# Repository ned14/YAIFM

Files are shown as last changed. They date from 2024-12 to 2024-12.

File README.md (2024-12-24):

# A remix of AndBu/YAIFM

His original can be found at: https://github.com/AndBu/YAIFM

The differences here:

1. No switches, we detect the motor stopping turning instead.
2. No switches means fewer parts need printing or assembling,
though we still use the motor housing and retention
clip untouched from AndBu.
3. Because we now rely on the blind 'jamming' to detect
when it is fully open, we need to use a metal cog as
the plastic isn't strong enough.
4. We have ESPHome figure out blind fully open after
first power on. It stores in flash what you tell it blind
fully closed is. After that, you can request '10% open'
or '50% closed' or whatever as usual within Home Assistant
and you'll get exactly that.

To tl;dr; the differences, we go for simpler hardware and
let the software do all the heavy lifting. I reckon total
BOM cost per blind is under €40 inc VAT delivered excluding
the 5v power supply (you can use any existing USB based
phone charger).

Thingiverse link: https://www.thingiverse.com/thing:6865302

Printables link: https://www.printables.com/model/1120003-ikea-fridans-motorisation

Detailed instructions: https://www.nedprod.com/Niall_stuff/vdiary/archives/1734888387.html

## Bill of Materials

1. A GA12-N20 motor with rotary encoder which runs at
50 RPM at 6v, and has around 1 kgf.cm of torque at normal
load. You probably will want one with as much torque
at stall as possible without consuming too much current,
this lets the motor 'push through' any badly furled blinds
or the 200 cm long model fully extended to 195 cm.
Aliexpress is probably your easiest choice here, there are
many GA12-N20 models to choose between. Mine cost about
€6 inc VAT delivered.

2. A DRV8833 dual H-Bridge motor driver. I used the one on
a breakout board called 'HW-627' which is very affordable,
also from Aliexpress for about €2 inc VAT delivered.

3. A ‘9 Teeth D Type’ metal cog which has an outer diameter
of 8 mm and is 7.4 mm long. The key measurement is between
the flat part of the D hole rising perpendicularly to the
topmost of the rounded part of the D hole – that needs to
be 2.4 mm if you want it loose, 2.3 mm if you want it tight.
For some reason, these can cost a lot or not at all
depending on the Aliexpress listing, so for reference mine
cost €0.82 inc VAT each delivered.

4. A 3D printer ideally capable of printing in bright white
ABS or ASA, but if not then one able to print in bright
white PETG. I wouldn't recommend PLA, the 3D printed parts
take a lot of repeated torsion stress and PLA doesn't do
well with that over time.

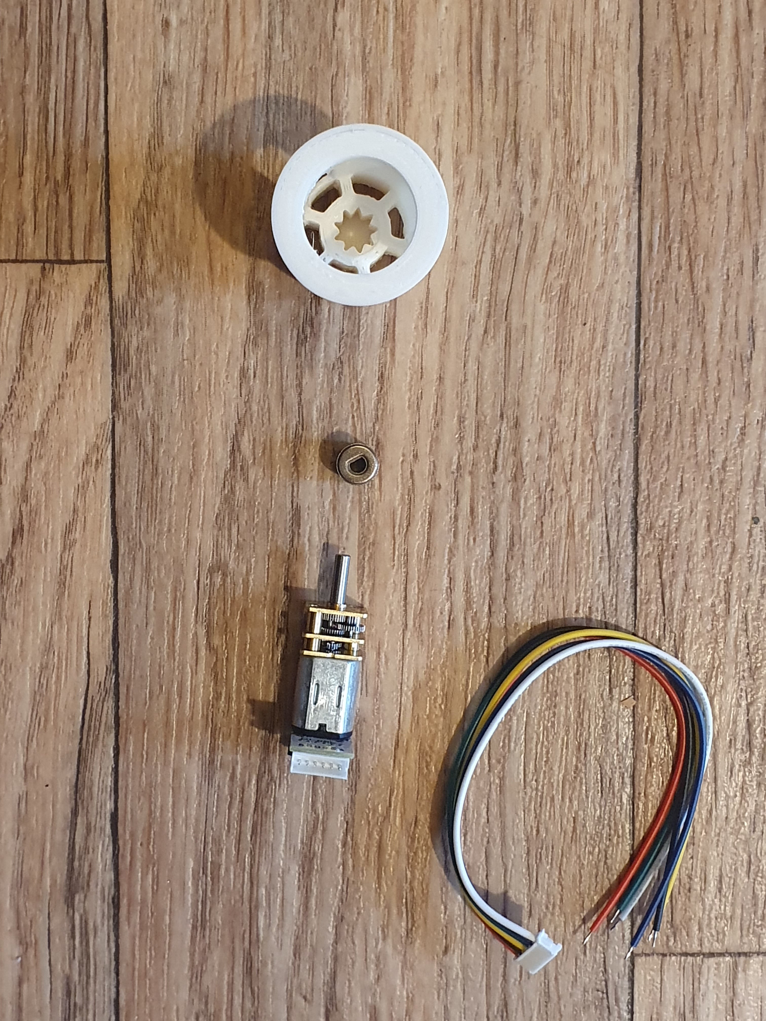
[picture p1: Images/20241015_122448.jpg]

 
5. Two steel washers to go between the cog/hub
and the motor to put as much horizontal load onto the motor
housing and not onto the motor shaft as possible. Most
steel washers are slightly curved, you can use that to
reduce the contact surface to minimum and reduce wear over
time. You can get these for pennies from anywhere.

6. Any microcontroller able to run ESPHome. The ESP32 Super
Mini costs about €1.50 inc VAT delivered and is perfectly
fine for this job. You will need a USB-C power supply for it.

7. Finally, your choice of IKEA Fridans blind. I tested the 180 cm
model from its full extension of 195 cm, and I would have
absolute confidence that there is enough motor power for the
200 cm blind. They cost between €18 and €28 inc VAT depending
on size.

https://github.com/user-attachments/assets/c323144f-e48f-4d71-8c1b-16eb3580f487

## Wiring

For the motor:

- Red: Motor forwards. Connect to OUT1 of the DRV8833 board.
- White: Motor backwards. Connect to OUT2 of the DRV8833 board.
- Blue: Common ground. Connect to the GND of your MCU.
- Black: 3.3v - 5v power supply for the encoder. Connect to
the 3.3v supply of your MCU.
- Green: Encoder A phase. Connect to an input of your MCU.
- Yellow: Encoder B phase. Connect to an input of your MCU.

For the DRV8833 'HW-627':

- IN1: Connect to an output of your MCU (forwards).
- IN2: Connect to an output of your MCU (backwards).
- VCC: Connect to the 5v supply of your MCU.
- EEP: Connect to the 5v supply of your MCU.
- OUT1: Connect to the Red Motor forwards of the motor.
- OUT2: Connect to the White Motor backwards of the motor.

## ESPHome

[You will find my firmware in this git repo](https://github.com/ned14/YAIFM/tree/main/ESPHome).
It is for an Olimex ESP32-PoE board. You **WILL** need to customise
it for your board.

What it does:

1. On boot from power off, slowly open the blind until
it stops moving. Store that as the new 'fully open'
state. Put the blind back to the last stored open/closed
position.

2. Publish to Home Assistant a Cover which can take
any open/close fraction between 0.0 and 1.0. We wind
the blind at full speed until we get close to the desired
position, then slow the blind to 25% speed until it is
exactly reached.

3. If during opening the blind stops, we currently
assume that this is the new fully open. A TODO FIXME is
to only do that if we are close to the currently known
'fully open' setting. To prevent motor burnout, we cut
the power if the motor stops turning for more than
160 milliseconds in either direction.

Note that it does still have a few bugs in it. Bug fixes
are welcome!

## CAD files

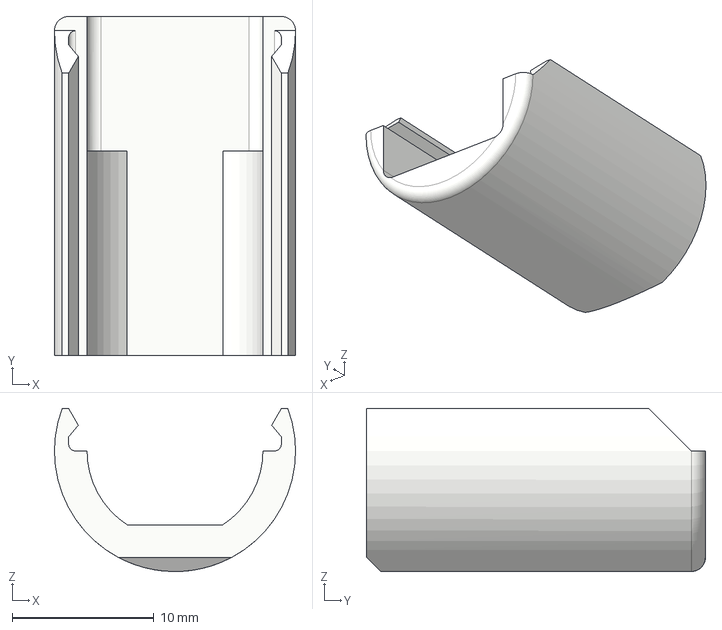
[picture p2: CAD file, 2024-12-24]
Original files/YAIFM_lid.step
17.0 x 23.9 x 11.5 mm

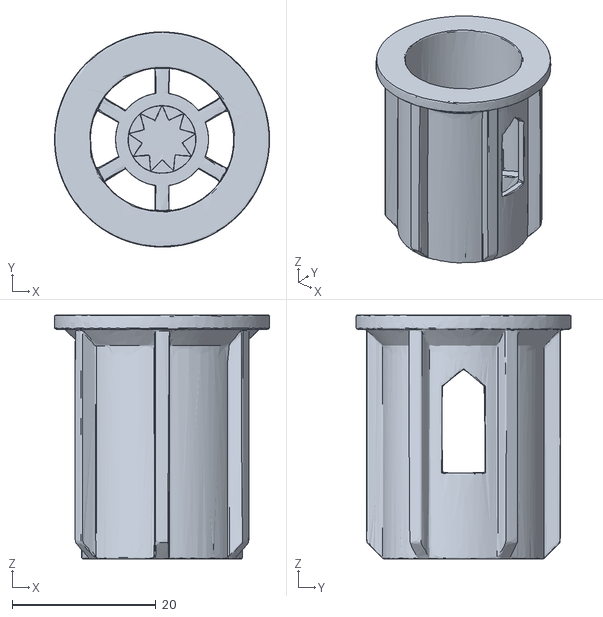
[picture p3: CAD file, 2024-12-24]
STL/hub2.stl
30.0 x 30.0 x 34.0

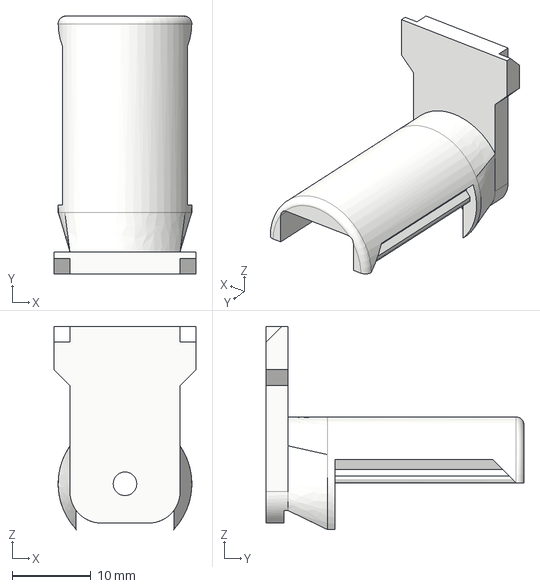
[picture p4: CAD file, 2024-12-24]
Original files/YAIFM_motor_holder.step
18.0 x 32.8 x 25.8 mm

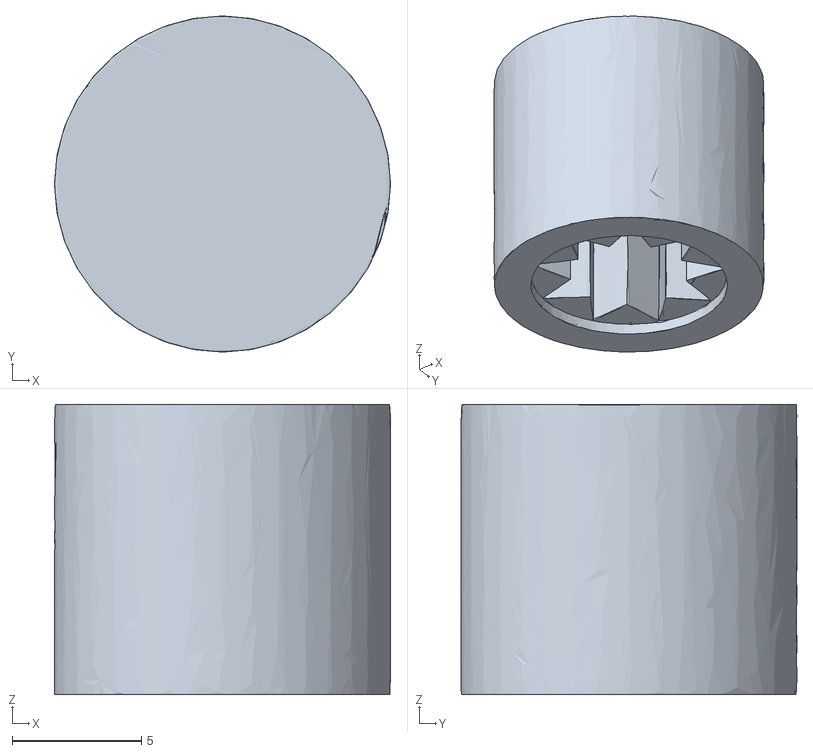
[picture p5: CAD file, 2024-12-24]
STL/mould2.stl
13.0 x 13.0 x 11.2

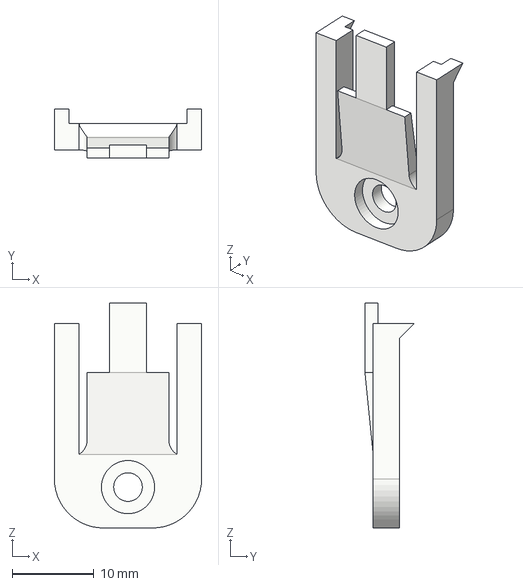
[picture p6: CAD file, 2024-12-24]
Original files/YAIFM_clip.step
18.0 x 6.00 x 27.5 mm

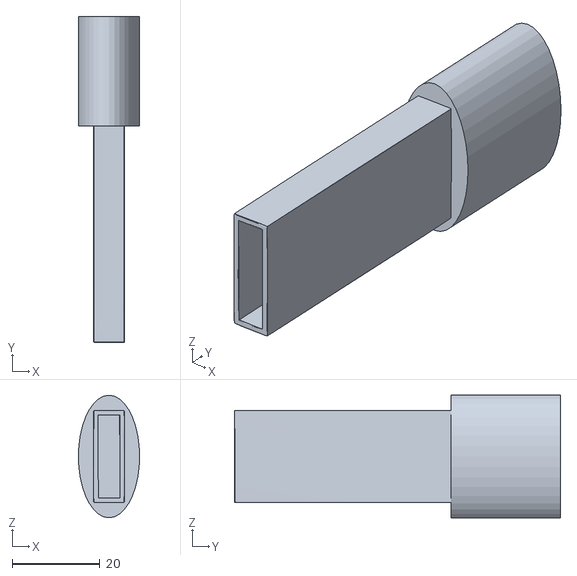
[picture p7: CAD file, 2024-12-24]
STL/blind_bottom_end.stl
14.0 x 74.5 x 28.0

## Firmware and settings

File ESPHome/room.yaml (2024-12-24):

### Inputs (4):
#   - GPI34 is button, defaults to pulled up
#   - GPI35 is battery voltage if jumper fused
#   - GPI36 is RXD for UART1 on UEXT, if not using UART then free to use
#   - GPI39 is external power supply voltage 47k/100k would yield 5.0v ~= 3.4v (max ADC is 3.12v) (HARDWIRED), so using this as a digital input makes more sense. The 47k resistor means this could be considered default pulled up.
#
### Outputs free to use (10):
#   - Not on UEXT: GPIO0, GPIO1, GPIO3, GPIO32, GPIO33
#   - On UEXT:     GPIO2, GPIO5, GPIO14, GPIO15
#   - GPIO4 is TXD for UART1 on UEXT, if not using UART then free to use
#
### Outputs generally in use (2):
#   - GPIO13 is I2C-SDA (UEXT)
#   - GPIO16 is I2C-SCL (UEXT)
#
### Outputs useful to keep free (2):
#   - GPIO1 is UART TXD for USB logging (always causes it to go high during early boot)
#   - GPIO3 is UART RXD for USB logging
#
#
# GPI34  (PINS) is (default pulled up)
# GPI35  (PINS) is wall dimmer switch level shifted down to TTL
# GPI36  (UEXT) is blind motor sensor B
# GPI39  (PINS) is (default pulled up)
#
# GPIO0  (PINS) is LED strip colour ?
# GPIO1  (PINS) is
# GPIO2  (UEXT) is blind motor PWM forwards?
# GPIO3  (PINS) is blind motor PWM backwards?
# GPIO4  (PINS) is blind motor sensor A
# GPIO5  (UEXT) is LED strip colour ?
# GPIO13 (UEXT) is I2C-SDA
# GPIO14 (UEXT) is LED strip colour ?
# GPIO15 (PINS) is LED strip colour ?
# GPIO16 (UEXT) is I2C-SCL
# GPIO32 (PINS) is ventilation fan forwards
# GPIO33 (PINS) is ventilation fan backwards


# If using the BTS7960 motor driver:
#   - PWM output for forwards
#   - PWM output for backwards
#   - Output for enable
#   - Optional: Input for forward current consumption (needs 1.7K resistor to produce a voltage range from a shunt to represent 0 - 5 amps due to 8500 scaling factor)
#   - Optional: Input for backwards current consumption (needs 1.7K resistor to produce a voltage range from a shunt to represent 0 - 5 amps due to 8500 scaling factor)

substitutions:
  # Irritatingly, blind_encoder reports NaN if it's never turned even if we ask for ALWAYS_ZERO
  blind_encoder_state: '(isnan(id(blind_encoder)->state) ? 0.0f : id(blind_encoder)->state)'
  current_blind_ratio: '((float)(${blind_encoder_state} - id(blind_encoder_abs_open_fully)) / (float) id(blind_encoder_rel_closed_fully))'
  blind_encoder_rel_slow_down: '(5000)'

esphome:
  name: room-prototype
  platform: ESP32
  board: esp32-poe
  on_boot:
    priority: 799  # Run this as soon as possible
    then:
      # Annoyingly the motor turns on boot
      - output.set_level:
          id: blind_forwards
          level: '0%'
      - output.set_level:
          id: blind_backwards
          level: '0%'
      # Wait for ethernet to establish, it itself waits 300 ms before doing anything
      - delay: 15s

      # When we first boot, we have no idea where the blind is. We could store to
      # flash, but the blind could have been changed during power off. Also,
      # when we first turn it on, I notice the motor turns for a bit before boot.
      # So drop it slighly first, then open it until it stops then we can
      # establish what 'fully open' means.
      #
      # Run it forwards for half a second
      - lambda: |-
          if(isnan(id(blind_encoder_rel_current)) || id(blind_encoder_rel_current) < 0.0f || id(blind_encoder_rel_current) > 1.0f) id(blind_encoder_rel_current) = 0.1f;
      - globals.set:
          id: old_blind_encoder_rel_current
          value: !lambda 'return id(blind_encoder_rel_current);'
      - logger.log:
          format: "On boot, blind closed fully = %d and setting before power loss = %.1f"
          args: [ 'id(blind_encoder_rel_closed_fully)', 'id(blind_encoder_rel_current)' ]
      - globals.set:
          id: blind_encoder_abs_open_fully
          value: '999999999'
      - script.execute:
          id: do_position_blind
          pos: 1.0  # open
          speed: 1.0
      - delay: 0.5s
      # Run it backwards until it stops turning
      - globals.set:
          id: blind_encoder_abs_open_fully
          value: '-999999999'
      - script.execute:
          id: do_position_blind
          pos: 0.0  # close
          speed: 1.0  # get it started
      - delay: 0.25s
      - script.execute:
          id: do_position_blind
          pos: 0.0  # close
          speed: 0.33  # take it easy after to reduce motor heating
      - script.wait:
          id: do_position_blind
      - delay: 1s
      # Now that blind_encoder_abs_open_fully has been determined,
      # restore the blind back to where it was
      - logger.log:
          format: "On boot, blind fully open determined to be %d. Restoring blind position to previous %f"
          args: [ 'id(blind_encoder_abs_open_fully)', 'id(old_blind_encoder_rel_current)' ]
      - script.execute:
          id: do_position_blind
          pos: !lambda 'return id(old_blind_encoder_rel_current);'
          speed: 1.0
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
